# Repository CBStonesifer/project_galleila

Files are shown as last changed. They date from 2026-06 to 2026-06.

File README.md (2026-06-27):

# Project Galleila — Beater-Bar BattleBot

A 3-pound (beetleweight) combat robot designed and built across the full hardware stack: mechanical CAD, PCB layout, and embedded firmware. The goal was a **reproducible end-to-end build process** — from CAD model to fabricated board to driving firmware — rather than peak performance. V2 will optimize for weight and combat performance.

**Skills demonstrated:** Fusion 360 / FDM prototyping · KiCad schematic + layout · custom footprint creation · Gerber fabrication output · ESP32 embedded C · RC PWM decode · LEDC motor PWM · skid-steer mixing

---

## Repo Structure

```
cad/          — 3D-printable chassis, wheels, and weapon (STL + 3MF)
pcb/          — KiCad schematic, layout, custom footprints, and gerbers
firmware/     — Arduino sketch for ESP32 (RC decode + motor mixing)
```

---

## Design Decisions

- **Beater bar weapon** — a relatively simple and proven design with high impact potential in the arena. The main weakness is being flipped; a lower profile in V2 addresses this directly.
- **Skid-steer drivetrain** — keeps mechanical complexity low while maintaining full mobility. No steering linkage, no Ackermann geometry, just two independently driven wheels.
- **Belt-driven weapon** — the GT2 20T/60T pulley ratio amplifies the motor's output speed to spin the beater bar faster than a direct-drive setup would allow.
- **Unitary printed body** — a single-piece chassis provides structural strength without mechanical interlocks between parts. Drive and weapon geometry were validated as separate prints first, then merged once the layout was confirmed.

---

## Bill of Materials

| # | Component | Part | Qty | Specs | Link |
|---|---|---|-----|---|---|
| 1 | MCU | ESP32 dev board | 1 | Dual-core 32-bit, 240 MHz, 3.3V, WiFi + BT | [Amazon](https://www.amazon.com/dp/B0C9TGJRPH) |
| 2 | Motor driver | DRV8833 | 3 | 1.5 A continuous, 2 A peak | [Amazon](https://www.amazon.com/dp/B0DXF6LZB1) |
| 3 | Buck regulator | LM2596 | 1 | 3–40V in, 1.5–35V adj out | [Amazon](https://www.amazon.com/dp/B0DBVYP91F) |
| 4 | Battery | 2S LiPo | 1 | 7.4V, 2000mAh, T-plug | [Amazon](https://www.amazon.com/dp/B0FCFVWS1K) |
| 5 | RC transmitter + receiver | — | 1 set | PWM out, 2-channel minimum | [Amazon](https://www.amazon.com/dp/B0FJDFJ38M) |
| 6 | Drive motors | 390 brushed | 2 | 6–12V, high-torque | [Amazon](https://www.amazon.com/dp/B01M58POHF) |
| 7 | Weapon motor | Brushed | 1 | TBD | [Amazon](https://www.amazon.com/dp/B0FXG6J3Z9) |
| 8 | Weapon belt drive | GT2 pulley + belt | 1 set | 20T / 60T, 8mm bore, 200mm belt | [Amazon](https://www.amazon.com/dp/B08QZ4365D) |
| 9 | Connectors | JST-XH 3-pin | 10 pairs | 2.54mm pitch, 26AWG, 200mm | [Amazon](https://www.amazon.com/dp/B0D3LVLMP9) |
| 10 | Print filament | PLA-CF 1.75mm | 1 spool | 1kg, carbon-fiber reinforced | [Amazon](https://www.amazon.com/dp/B0D7VV1YC7) |

---

## CAD

**Tool:** Fusion 360 → FDM (PLA-CF)  
**All parts:** `cad/` — available as both `.stl` and `.3mf`

| File | Description |
|---|---|
| `chassis.stl` / `.3mf` | Unitary chassis: electronics bay, drive motor mounts, weapon mount |
| `drive_wheel.stl` / `.3mf` | Drive wheels (print ×2) |
| `weapon_impactor.stl` / `.3mf` | Beater-bar weapon impactor |

Drive and weapon subsystems were first validated as separate prints, then consolidated into a single `chassis` once geometry was confirmed. Total bot target: ≤ 3 lb; drive motors are the dominant mass — body is designed to be as light as possible.

| | |
|---|---|
| Fusion 360 chassis render | Assembled Mark 1 |
| *Fusion 360 render — `chassis`* | *Mark 1 assembled — PCB and drive motor installed* |

---

## ECAD

**Tool:** KiCad 7  
**Fabrication output:** `pcb/gerbers/battlebot_gerbers_v1.zip` — ready to send to any fab house

### Files

| File | Purpose |
|---|---|
| `pcb/BattleBot.kicad_sch` | Full schematic |
| `pcb/BattleBot.kicad_pcb` | Board layout |
| `pcb/BattleBot-parts.kicad_sym` | Custom KiCad symbol library |
| `pcb/BattleBot.pretty/` | Custom footprint library (6 footprints) |
| `pcb/gerbers/` | Gerber + drill files |

### Power Architecture

```
LiPo ──→ LM2596 (buck) ──→ 5V ──→ ESP32-WROVER-E
LiPo ──→ DRV8833 (×3) ──→ Drive motors + weapon motor (direct VBAT)
```

### GPIO Pin Assignments

| Signal | ESP32 GPIO |
|---|---|
| RC Steering (PWM in) | 35 |
| RC Throttle (PWM in) | 34 |
| RC Weapon toggle (PWM in) | 18 |
| Left motor IN1 | 25 |
| Left motor IN2 | 26 |
| Right motor IN1 | 27 |
| Right motor IN2 | 14 |
| Weapon motor IN1 | 2 |
| Weapon motor IN2 | 15 |
| nFAULT (DRV8833) | 33 |
| UART0 debug | 115200 baud |

### Custom Footprints

All footprints in `pcb/BattleBot.pretty/` were drawn from datasheets:

| Footprint | File |
|---|---|
| ESP32-WROVER-E | `ESP32-WROVER-E.kicad_mod` |
| DRV8833 | `DRV8833.kicad_mod` |
| LM2596 | `LM2596.kicad_mod` |
| RC Receiver | `Reciever.kicad_mod` |
| 3-pin connector | `3Pin-Connector.kicad_mod` |
| Test point pad | `Testpoint-Pad.kicad_mod` |

KiCad schematic
*Schematic — `BattleBot.kicad_sch`*

| | |
|---|---|
| KiCad PCB layout | PCB 3D render |
| *Layout — `BattleBot.kicad_pcb`* | *KiCad 3D render* |

Populated PCB
*Fabricated and populated board*

---

## Firmware

**Toolchain:** Arduino IDE + ESP32 board support package  
**Board target:** ESP32 Wrover Module  
**Sketch:** `firmware/signal_driver/signal_driver.ino`

### Control Loop

```
loop()
  ├── readSteering()   — pulseIn GPIO 35 → map to [-100, 100] → deadband
  ├── readThrottle()   — pulseIn GPIO 34 → map to [-100, 100] → deadband
  ├── pulseIn GPIO 18  — weapon toggle (> 1500 µs = ON)
  ├── mixAndDrive()    — skid-steer mix → setMotor() → LEDC PWM duty
  ├── setWeapon()      — full speed on WEAPON_IN1/IN2 when armed
  └── fault poll       — read GPIO 33 nFAULT → Serial.print @ 115200
```

### Motor Mixing

- **Straight:** `left = right = throttle`
- **Driving turn:** inner wheel = `throttle × (TURN_MIX_RATIO / 100)`
- **Spin-in-place:** `left = +steering`, `right = −steering`

### Calibration Constants

| Constant | V1 Value | Purpose |
|---|---|---|
| `STEERING_MIN` | 965 µs | Min receiver pulse |
| `STEERING_MAX` | 1882 µs | Max receiver pulse |
| `THROTTLE_MIN` | 1055 µs | Min throttle pulse |
| `THROTTLE_IDLE` | 1565 µs | Neutral position |
| `THROTTLE_MAX` | 2000 µs | Max throttle pulse |
| `DEADBAND` | 5 | Noise rejection around neutral |
| `TURN_MIX_RATIO` | 50 | Inner-wheel scaling (0–100) |
| `PWM_FREQ` | 20,000 Hz | LEDC motor PWM frequency |
| `PWM_RES` | 8-bit | Duty cycle range (0–255) |

> These constants are radio-specific. Re-measure pulse widths for your transmitter before first drive.

### Flash Instructions

1. Install ESP32 board support in Arduino IDE
2. Open `firmware/signal_driver/signal_driver.ino`
3. Select **ESP32 Wrover Module**, set the correct COM port
4. Update calibration constants for your RC radio
5. Upload

---

## Testing & Validation

The bot was driven under full battery power with all systems operating independently:

- **Drive** — successfully accelerated, turned, and reversed at varying speeds under RC control.
- **Weapon** — spun up to full speed and was toggled on and off from the transmitter.
- **Carpet performance** — struggled on carpet. The wheels lacked grip, and the design relies on the body sliding along the ground to stay low against opponents — which doesn't work well on high-friction surfaces.
- **Battery connector** — the 3-pin JST-XH plugs do not physically prevent reverse polarity insertion. Connecting the battery backwards is easy to do and will damage the board.

---

## Known Issues & Further Improvements (V2)

- **Chassis Side Overhangs** — the overhangs on the side were quickly added to thicken the width of the walls to strengthen the bot, and for style. They provide a grip for another bot to easily flip the vehicle. The next design should minimize the gap between the side edges and the ground.
- **Hard Power Cut-Off** — as per NHRL rules, the bot requires a quick physical power disconnect to disable movement and weapon systems, not just a code deactivation.
- **Hardened weapon impactor** — machine or print in PETG/nylon/polycarbonate; evaluate a metal impactor for the beater bar.
- **Weight optimization** — the current design is 2.76 lbs, which leaves room to upgrade/add additional parts (i.e. the weapon material should be metal).
- **Optimize print settings** — a final print with more granular layer heights and higher infill will strengthen the hull.
- **A Roof** — the top of the bot needs a solid roof that could also act as a battery retainer. Batteries are currently loose within the chassis.
- **Sweet Paint Job** — the bot needs some decals and a layer of spray paint to make it look more threatening.
- **Wheel Grips and Covers** — the wheels are exposed and use electrical tape for grip. They must be better protected, as immobility is an immediate loss in the arena. A set of proper tires would help with mobility, and the front shovel can catch on uneven surfaces.
- **Beater Bar orientation is reversed** — the edge of the beater bar faces inward, counter to the direction the bar spins. Opposing robots are hit with the blunt edge of the weapon rather than the sharp, scraping side that should brush close to the ground.
---

## Tools Required

- **3D printer** — Bambu A1 (or equivalent FDM printer capable of PLA-CF)
- **Soldering iron** — flux is mandatory; makes the joints significantly cleaner and easier
- **Wire stripper**
- **Extra header pins**
- **Assorted screws and a screwdriver**

---

## Status

| Version | Status | Focus |
|---|---|---|
| V1 | Complete | Cost-optimized, full-stack process established |
| V2 | Planned | Weight/performance, hardened materials, active fault handling |

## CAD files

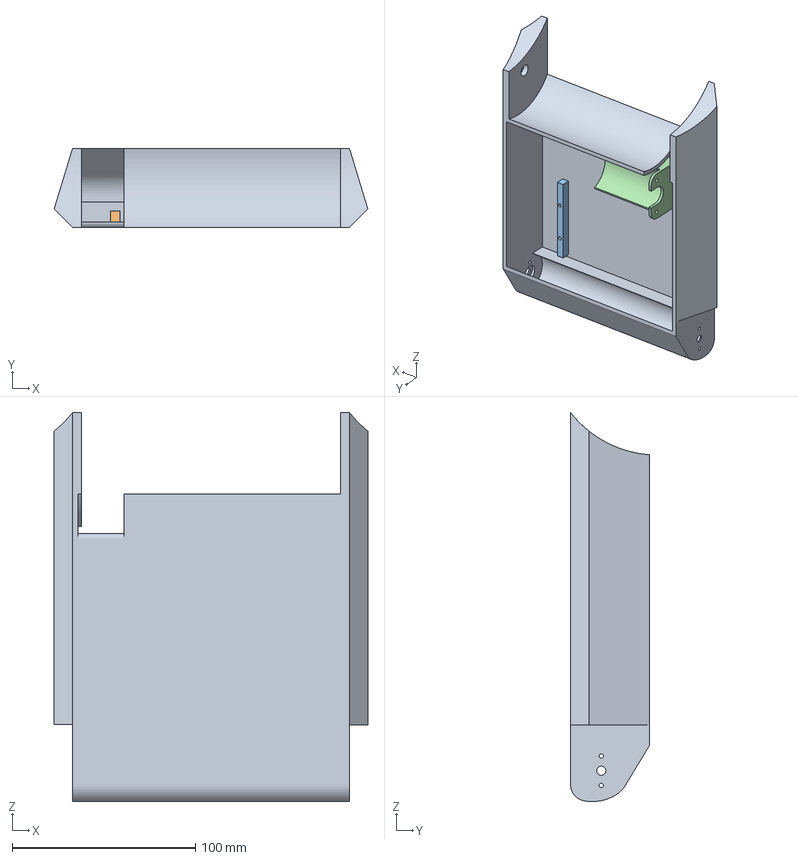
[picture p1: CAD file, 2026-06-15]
cad/full_body.3mf
171.0 x 43.0 x 212.0 mm

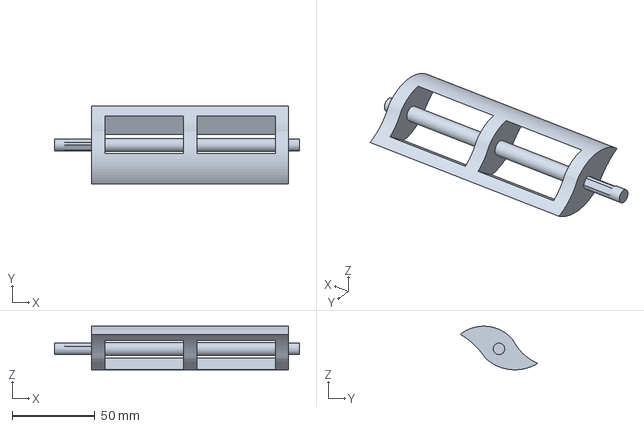
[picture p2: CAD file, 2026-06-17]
cad/BeaterBar_v2.3mf
148.0 x 46.8 x 26.3 mm

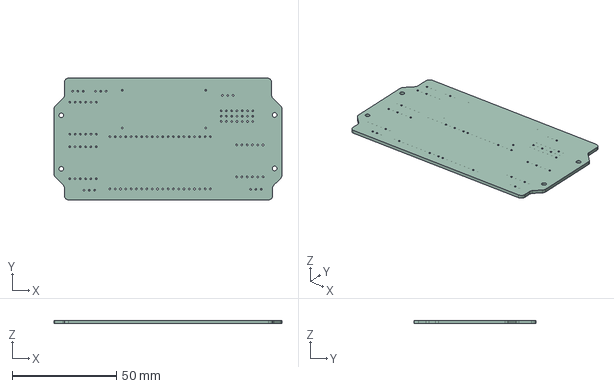
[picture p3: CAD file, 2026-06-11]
cad/boardv2.step
109.5 x 58.5 x 1.51 mm

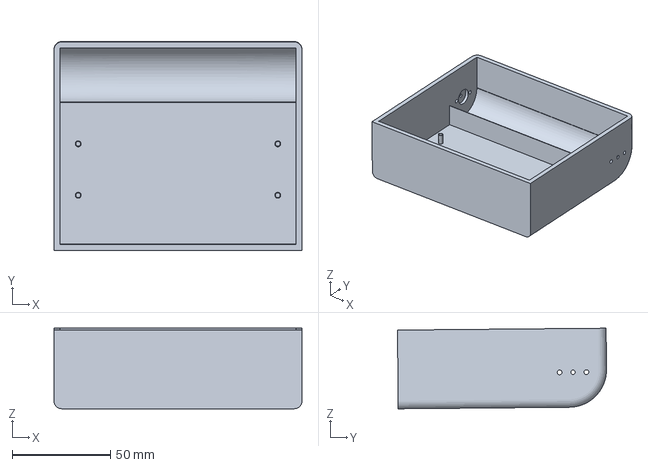
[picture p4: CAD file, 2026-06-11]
cad/Body.3mf
126.0 x 106.2 x 41.0 mm

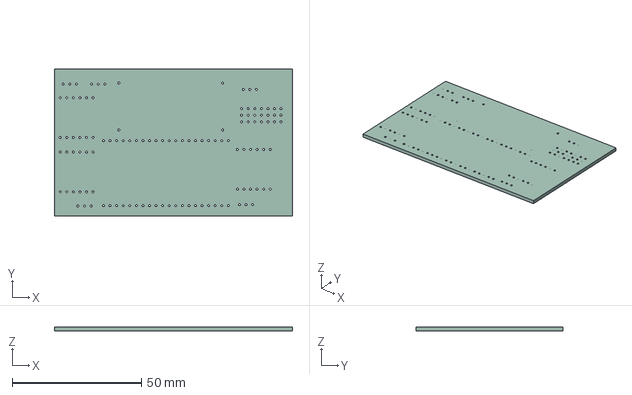
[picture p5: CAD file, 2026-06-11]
cad/boardv1.step
92.0 x 57.0 x 1.51 mm

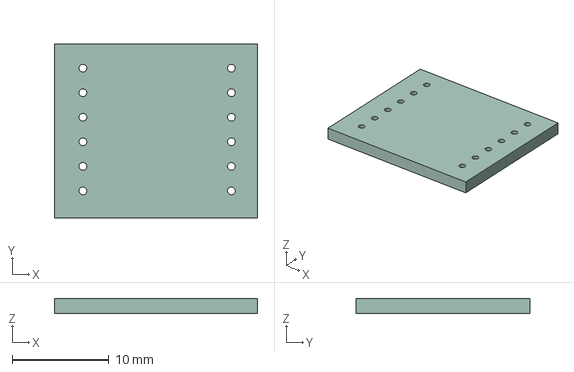
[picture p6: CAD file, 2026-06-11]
cad/DRV8333-shape.step
21.0 x 18.0 x 1.51 mm

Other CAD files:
cad/BeaterBar_v2.f3d
cad/DRV8333-shape.3mf
cad/full_body.stl

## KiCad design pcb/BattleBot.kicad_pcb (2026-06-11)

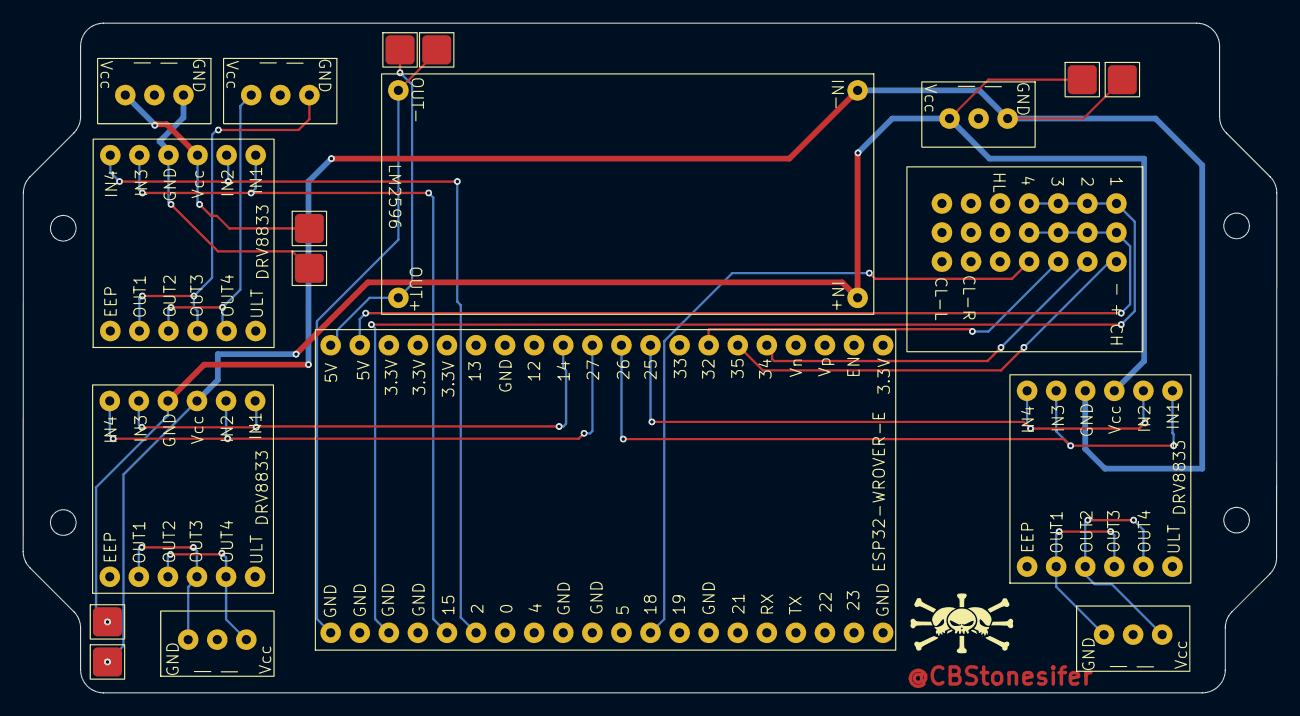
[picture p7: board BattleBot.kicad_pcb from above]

Board: 4 copper layers, 109.5 x 58.5 mm, 19 parts (0 on the bottom side), 24 nets.

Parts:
B1: 3Pin-Connector
B2: Vcc; 3Pin-Connector
Buck1: LM2596
J1: WeaponMotor; 3Pin-Connector
J2: Motor1; 3Pin-Connector
J3: Motor2; 3Pin-Connector
MD_TP1, MD_TP2, MD_TP3, MD_TP4, MD_TP5, MD_TP6, MD_TP7, MD_TP8: Motor Driver Test Point 1; Testpoint-Pad
MicroController1: ESP32-WROVER-E
MotorDriver1, MotorDriver2: DRV8833
Receiver1: Reciever
WeaponDriver1: DRV8833

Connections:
unnamed: B1.3 (GND), MD_TP7.1 (1_1), WeaponDriver1.9 (GND)
unnamed: B1.1 (Vcc), MD_TP8.1 (1_1), WeaponDriver1.10 (VCC)
unnamed: B2.3 (GND), Buck1.2 (IN-), MD_TP2.1 (1_1), MD_TP3.1 (1_1), MotorDriver1.9 (GND), MotorDriver2.9 (GND)
unnamed: B2.1 (Vcc), Buck1.1 (IN+), MD_TP1.1 (1_1), MD_TP4.1 (1_1), MotorDriver1.10 (VCC), MotorDriver2.10 (VCC)
unnamed: Buck1.3 (OUT+), MD_TP5.1 (1_1), MicroController1.20 (5V)
unnamed: Buck1.4 (OUT-), MD_TP6.1 (1_1), MicroController1.21 (GND)
unnamed: J1.1, WeaponDriver1.3 (OUT2), WeaponDriver1.5 (OUT4)
unnamed: J1.3, WeaponDriver1.2 (OUT1), WeaponDriver1.4 (OUT3)
unnamed: J2.1, MotorDriver1.3 (OUT2), MotorDriver1.5 (OUT4)
unnamed: J2.3, MotorDriver1.2 (OUT1), MotorDriver1.4 (OUT3)
unnamed: J3.1, MotorDriver2.3 (OUT2), MotorDriver2.5 (OUT4)
unnamed: J3.3, MotorDriver2.2 (OUT1), MotorDriver2.4 (OUT3)
unnamed: MicroController1.26 (GPIO2), WeaponDriver1.7 (IN4), WeaponDriver1.11 (IN2)
unnamed: MicroController1.12 (GPIO14), MotorDriver1.8 (IN3), MotorDriver1.12 (IN1)
unnamed: MicroController1.25 (GPIO15), WeaponDriver1.8 (IN3), WeaponDriver1.12 (IN1)
unnamed: MicroController1.32 (GPIO18), Receiver1.12 (SIG_4)
unnamed: MicroController1.9 (GPIO25), MotorDriver2.7 (IN4), MotorDriver2.11 (IN2)
unnamed: MicroController1.10 (GPIO26), MotorDriver2.8 (IN3), MotorDriver2.12 (IN1)
unnamed: MicroController1.11 (GPIO27), MotorDriver1.7 (IN4), MotorDriver1.11 (IN2)
unnamed: MicroController1.7 (GPIO32), Receiver1.9 (SIG_3)
unnamed: MicroController1.5 (GPIO34), Receiver1.6 (SIG_2)
unnamed: MicroController1.6 (GPIO35), Receiver1.3 (SIG_1)
unnamed: MicroController1.23 (GND), Receiver1.1 (GND_1), Receiver1.4 (GND_2), Receiver1.7 (GND_3), Receiver1.10 (GND_4)
unnamed: MicroController1.19 (5V), Receiver1.2 (VCC_1), Receiver1.5 (VCC_2), Receiver1.8 (VCC_3), Receiver1.11 (VCC_4)

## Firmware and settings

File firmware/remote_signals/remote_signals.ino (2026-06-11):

// ── Pins ──────────────────────────────────────────────────────────────────
const int STEERING_PIN = 35;
const int THROTTLE_PIN = 34;

const int MOTOR_L_IN1 = 25;
const int MOTOR_L_IN2 = 26;
const int MOTOR_R_IN1 = 27;
const int MOTOR_R_IN2 = 14;

const int FAULT_PIN = 33;

// ── PWM config ────────────────────────────────────────────────────────────
const int PWM_FREQ = 20000;
const int PWM_RES  = 8;

// ── Receiver calibration (µs) ─────────────────────────────────────────────
const int STEERING_MIN  = 965;
const int STEERING_MAX  = 1882;

const int THROTTLE_MIN  = 1055;
const int THROTTLE_IDLE = 1565;
const int THROTTLE_MAX  = 2000;

// ── Tuning ────────────────────────────────────────────────────────────────
const int DEADBAND       = 5;
const int TURN_MIX_RATIO = 50;

// ─────────────────────────────────────────────────────────────────────────
void setup() {
  Serial.begin(115200);
  delay(500);
  Serial.println("\n=== RC CAR STARTING ===");

  pinMode(STEERING_PIN, INPUT);
  pinMode(THROTTLE_PIN, INPUT);
  pinMode(FAULT_PIN, INPUT_PULLUP);

  ledcAttachChannel(MOTOR_L_IN1, PWM_FREQ, PWM_RES, 0);
  ledcAttachChannel(MOTOR_L_IN2, PWM_FREQ, PWM_RES, 1);
  ledcAttachChannel(MOTOR_R_IN1, PWM_FREQ, PWM_RES, 2);
  ledcAttachChannel(MOTOR_R_IN2, PWM_FREQ, PWM_RES, 3);

  ledcWrite(MOTOR_L_IN1, 0);
  ledcWrite(MOTOR_L_IN2, 0);

  Serial.println("Setup complete.");
}

// ── Write a signed speed (-100..100) to one motor ─────────────────────────
void setMotor(int pinA, int pinB, int speed) {
  speed = constrain(speed, -100, 100);
  int duty = map(abs(speed), 0, 100, 0, 255);
  if (speed > 0) {
    ledcWrite(pinA, duty);
    ledcWrite(pinB, 0);
  } else if (speed < 0) {
    ledcWrite(pinA, 0);
    ledcWrite(pinB, duty);
  } else {
    ledcWrite(pinA, 0);
    ledcWrite(pinB, 0);
  }
}

// ── Deadband ──────────────────────────────────────────────────────────────
int applyDeadband(int value) {
  return abs(value) <= DEADBAND ? 0 : value;
}

// ── Read steering: -100 (left) .. 0 .. +100 (right) ──────────────────────
int readSteering() {
  int pulse    = pulseIn(STEERING_PIN, HIGH, 25000);
  int steering = map(pulse, STEERING_MIN, STEERING_MAX, -100, 100);
  return applyDeadband(constrain(steering, -100, 100));
}

// ── Read throttle: -100 (full reverse) .. 0 .. +100 (full forward) ────────
int readThrottle() {
  int pulse = pulseIn(THROTTLE_PIN, HIGH, 25000);
  int throttle;
  if (pulse >= THROTTLE_IDLE) {
    throttle = map(pulse, THROTTLE_IDLE, THROTTLE_MAX, 0, 100);
  } else {
    throttle = map(pulse, THROTTLE_MIN, THROTTLE_IDLE, -100, 0);
  }
  return applyDeadband(constrain(throttle, -100, 100));
}

// ── Motor mixing ──────────────────────────────────────────────────────────
void mixAndDrive(int throttle, int steering) {
  int leftSpeed, rightSpeed;

  if (throttle == 0) {
    leftSpeed  =  steering;
    rightSpeed = -steering;
  } else {
    int inner = (throttle * TURN_MIX_RATIO) / 100;
    if (steering > 0) {
      leftSpeed  = throttle;
      rightSpeed = inner;
    } else if (steering < 0) {
      leftSpeed  = inner;
      rightSpeed = throttle;
    } else {
      leftSpeed  = throttle;
      rightSpeed = throttle;
    }
  }

  setMotor(MOTOR_L_IN1, MOTOR_L_IN2, leftSpeed);
  setMotor(MOTOR_R_IN1, MOTOR_R_IN2, rightSpeed);
}

// ─────────────────────────────────────────────────────────────────────────
void loop() {
  int steering = readSteering();
  int throttle  = readThrottle();
  bool fault    = digitalRead(FAULT_PIN) == LOW;

  mixAndDrive(throttle, steering);

  Serial.print("ST: ");     Serial.print(steering);
  Serial.print("  TH: ");   Serial.print(throttle);
  Serial.print("  ULT: ");  Serial.println(fault ? "** FAULT **" : "OK");

  delay(20);
}

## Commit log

2026-06-11 Initial commit: organize BattleBot project files
    [BattleBot-B_Mask.gbs, BattleBot-B_Paste.gbp, BattleBot-B_SilkS.gbo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]
2026-06-17 beater bar v2
    [BeaterBar_v2.3mf, BeaterBar_v2.f3d]
